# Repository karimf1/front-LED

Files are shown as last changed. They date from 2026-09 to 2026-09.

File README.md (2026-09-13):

# Front LED Light-Bar Holder — Electric Rover

A bracket that carries a Ø50 × 900 mm LED light bar across the front of an
electric rover: a 2 m rail bolted to two chassis pick-up points, with two
split clamps holding the light bar 45 mm above it.

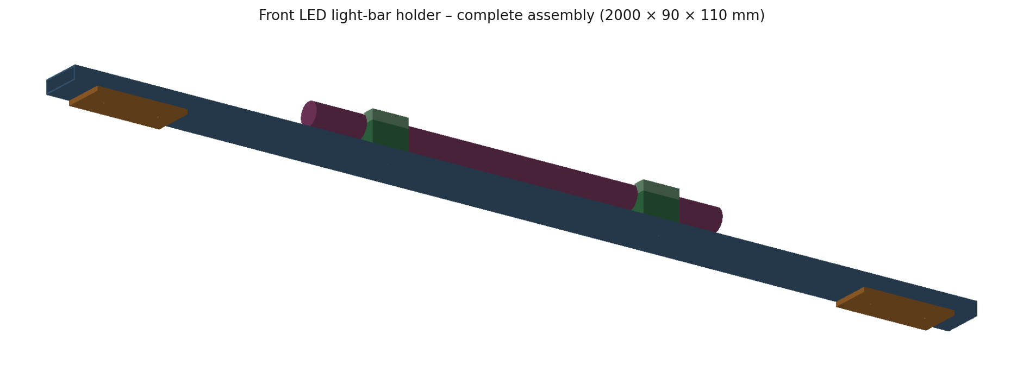
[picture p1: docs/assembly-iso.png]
Assembly


---

## Key features

- **A fully parametric assembly.** Every dimension lives in one parameter block;
  change a number and the whole model — solids, holes, fastener positions,
  drawing sheet — regenerates.
- **A stiffness-driven rail section**, chosen by running the beam case rather
  than by picking a plausible-looking bar.
- **Crush tubes at every bolt**, so the closed rail section survives being
  torqued up.
- **A 2 mm EPDM liner between clamp and light bar**, with the bore opened to
  suit, isolating aluminium from the light-bar housing.
- **An A3 manufacturing drawing generated from the same source as the 3D
  model**, so the sheet and the solids cannot disagree.
- **Two exchangeable rail sections** — the RHS as built, and the original flat
  bar — selectable from one parameter for anyone who wants to see the
  comparison.

---

## The completed design

Origin is the centre of the rail, on its top face. **+X** along the rail,
**+Y** forward (the way the light points), **+Z** up.

| Item | Description | Qty | Material |
|---|---|---|---|
| 1 | Rail, RHS 90 × 30 × 3, 2000 long | 1 | 6061-T6 |
| 2 | Chassis mounting plate 200 × 90 × 10, 2 × Ø11 @ 120 | 2 | 6061-T6 |
| 3 | Clamp saddle 80 × 90 × 45, Ø54 bore | 2 | 6061-T6 |
| 4 | Clamp strap 80 × 90 × 22, Ø54 bore | 2 | 6061-T6 |
| 5 | Crush tube 20 OD × 11 ID × 24 | 4 | 304 stainless |
| 6 | Crush tube 14 OD × 6.6 ID × 24 | 4 | 304 stainless |
| 7 | Bolt M10 × 60, nut + washers | 4 | A2-70 |
| 8 | Bolt M6 × 100, nyloc + washers | 4 | A2-70 |
| 9 | EPDM liner 2 thk × 170 × 80 | 2 | EPDM 60 Sh |
| 10 | LED light bar Ø50 × 900 *(reference)* | 1 | purchased |

Envelope **2000 × 90 × 110 mm**, fabricated mass **6.54 kg** (6.28 kg aluminium
+ 0.26 kg stainless), light bar and fasteners excluded.

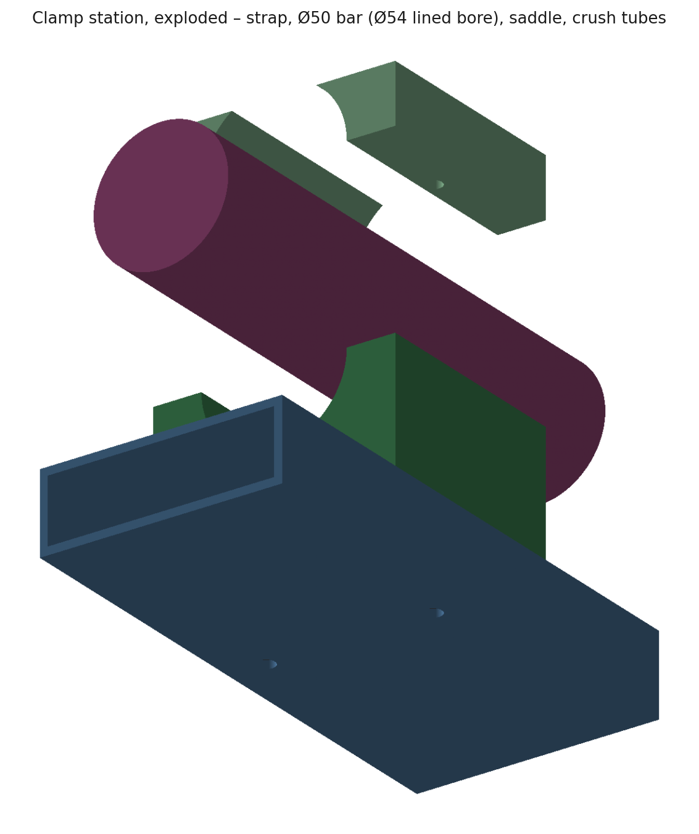
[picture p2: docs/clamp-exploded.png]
Clamp exploded


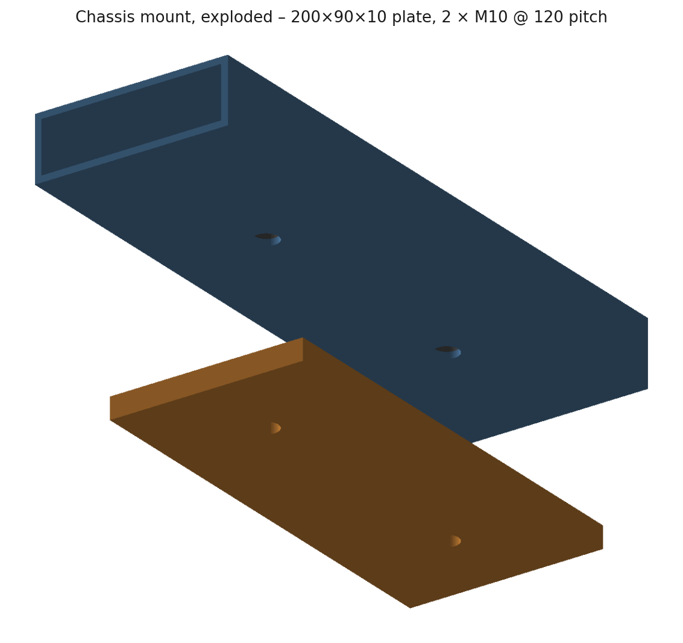
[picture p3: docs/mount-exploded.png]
Chassis mount exploded


## The manufacturing drawing

An A3 sheet drawn 1:1 in millimetres — front elevation and plan at 1:10,
section A-A through a clamp and the chassis plate detail at 1:2, with a title
block, BOM and notes. Dimensions carry a `DIMLFAC` override, so every one reads
the true size of the part despite the view scale.

It exists twice, from the same source:

- **on the `A3 DRAWING` layout of the 3D DWG** — paper space, A3 page already
  set up, so the finished file carries the sheet and the model together.
- **`cad/front-led-mount-drawing.dxf`** — the same sheet in model space as a
  standalone file, for importing into someone else's drawing or handing to a
  shop that does not want the 3D model.

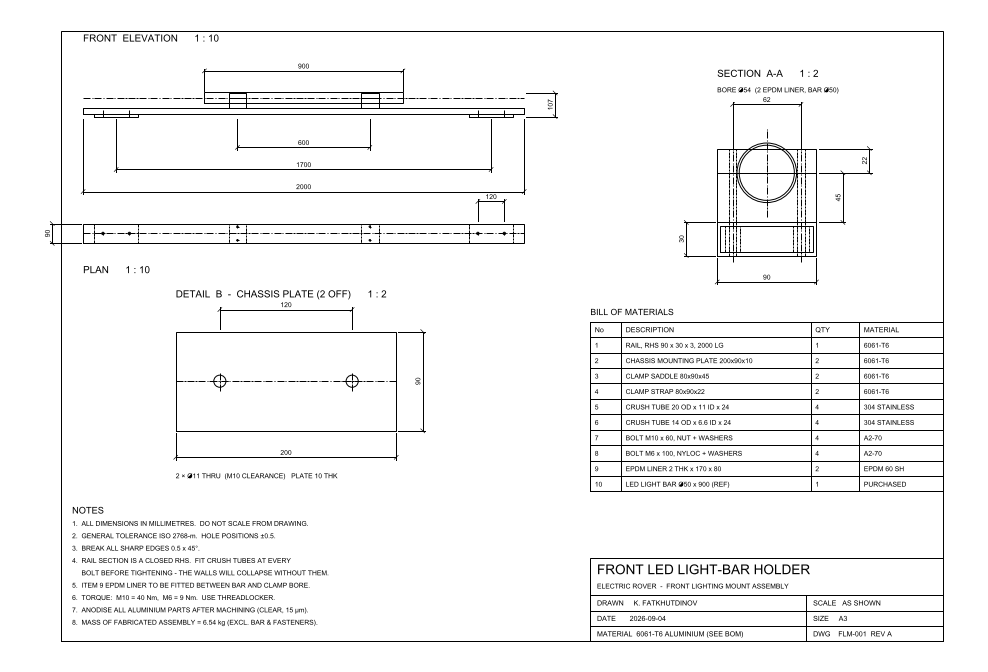
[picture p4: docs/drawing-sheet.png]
Drawing sheet


## Why the model is built by script

The assembly is described by an AutoLISP program rather than placed by hand, and
the parameters live in one block at the top of it. That choice is what makes
decision 1 possible: swapping the rail from flat bar to RHS is one symbol, and
the plates, the crush tubes, the bolt lengths and the drawing sheet all follow.
Hand-modelled, that comparison would have been a day's rework and would
therefore not have been made.

The same parameters are mirrored in `params.py`, which drives the drawing
generator — so the sheet's dimensions come from the same numbers as the solids
rather than from someone reading them off the model.

---

## Next steps and possible improvements

- **Confirm the light bar's actual mass**; 2.5 kg is assumed. Deflection and
  first-mode frequency scale roughly with √mass, so a 4 kg bar moves the 26 Hz
  result to about 21 Hz.
- **Run a proper modal analysis if the rover sees sustained excitation above
  ~15 Hz.** The 26 Hz figure is a hand calculation on a uniform beam with
  distributed mass; the real structure has two discrete clamp masses and a bar
  that contributes its own stiffness.
- **Add a slotted adjustment in the saddle** if the light bar needs aiming after
  mounting. The aim is presently fixed by the bore axis, which means getting it
  wrong is a re-machining job rather than a spanner job.
- **Reconsider the mount span.** 1700 mm between supports is inherited from the
  original construction lines. Moving the plates outboard is the cheapest
  remaining stiffness gain available — deflection goes as span⁴ between
  supports — and costs nothing but chassis pick-up points.
- **Check the bolted joint properly.** The crush tubes make the joint sane, but
  no preload, slip or bearing calculation has been done; the M10s are sized by
  convention rather than by analysis.
- **Add a drainage path.** A 2 m closed section pointing into the weather on a
  rover will collect water at one end. A small hole at the low point costs
  nothing and is easier to add now than after anodising.
- **Corrosion at the aluminium/stainless interface.** The crush tubes sit
  directly in the aluminium rail. For anything other than dry-weather use, an
  insulating washer or a coated sleeve is worth the extra part number.

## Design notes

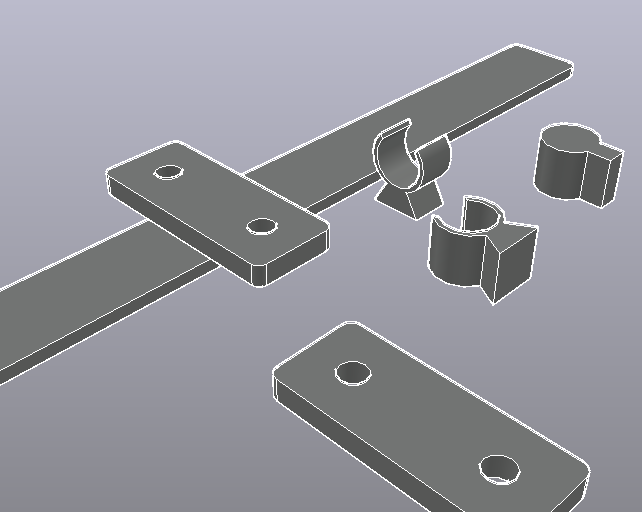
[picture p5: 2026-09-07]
docs/original-model-preview.png

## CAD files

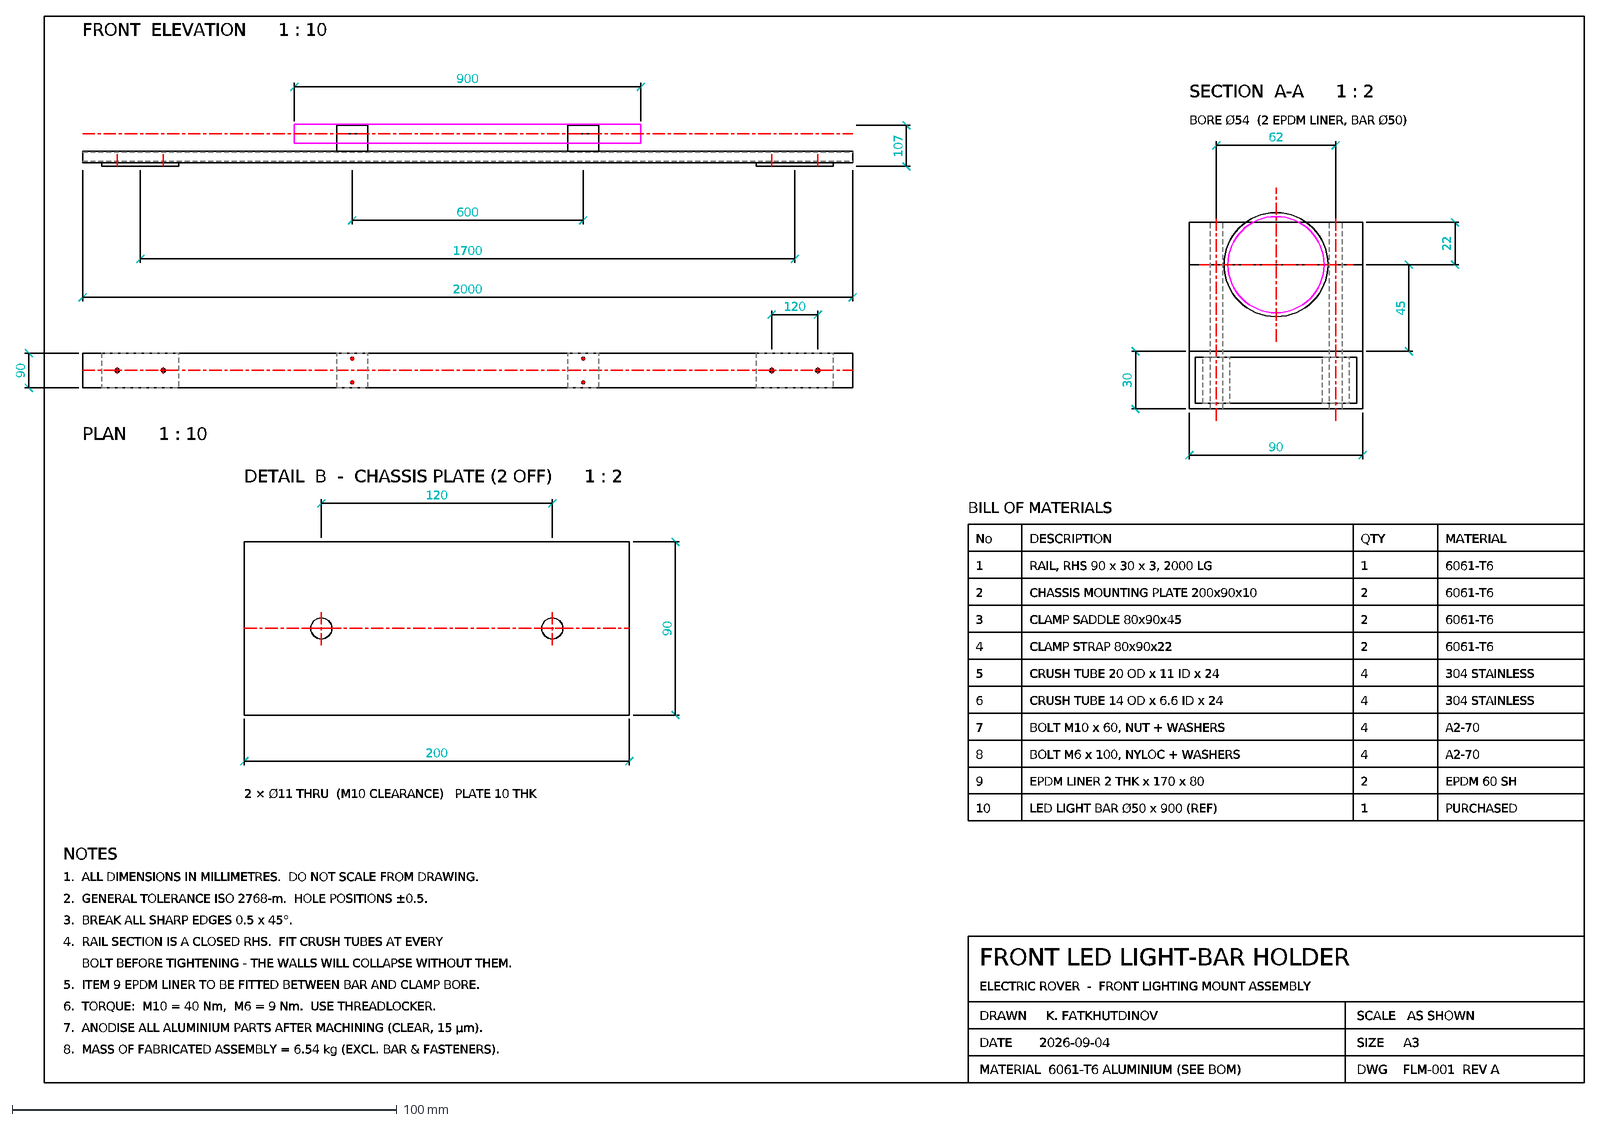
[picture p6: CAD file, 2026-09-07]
front-led-mount-sheet-A3.dxf
2000
1700
600
900
107
FRONT ELEVATION 1 : 10
90
120
PLAN 1 : 10
62
30
45
22
SECTION A-A 1 : 2
BORE Ø54 (2 EPDM LINER, BAR Ø50)
200
DETAIL B - CHASSIS PLATE (2 OFF) 1 : 2
2 × Ø11 THRU (M10 CLEARANCE) PLATE 10 THK
FRONT LED LIGHT-BAR HOLDER
ELECTRIC ROVER - FRONT LIGHTING MOUNT ASSEMBLY
DRAWN K. FATKHUTDINOV
DATE 2026-09-04
MATERIAL 6061-T6 ALUMINIUM (SEE BOM)
SCALE AS SHOWN
SIZE A3
DWG FLM-001 REV A
No
DESCRIPTION
QTY
MATERIAL
1
RAIL, RHS 90 x 30 x 3, 2000 LG
6061-T6
2
CHASSIS MOUNTING PLATE 200x90x10
3
CLAMP SADDLE 80x90x45
4
CLAMP STRAP 80x90x22
5
CRUSH TUBE 20 OD x 11 ID x 24
304 STAINLESS
6
CRUSH TUBE 14 OD x 6.6 ID x 24
7
BOLT M10 x 60, NUT + WASHERS
A2-70
8
BOLT M6 x 100, NYLOC + WASHERS
9
EPDM LINER 2 THK x 170 x 80
EPDM 60 SH
10
LED LIGHT BAR Ø50 x 900 (REF)
PURCHASED
BILL OF MATERIALS
NOTES
1. ALL DIMENSIONS IN MILLIMETRES. DO NOT SCALE FROM DRAWING.
2. GENERAL TOLERANCE ISO 2768-m. HOLE POSITIONS ±0.5.
3. BREAK ALL SHARP EDGES 0.5 x 45°.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

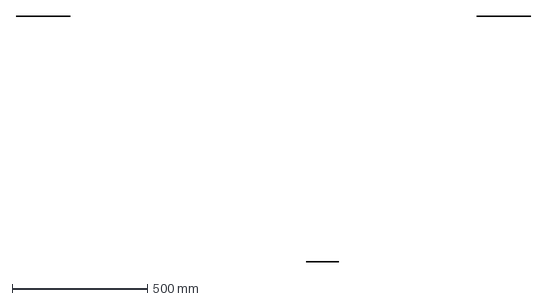
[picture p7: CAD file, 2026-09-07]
front-LED_ORIGINAL-decoded.dxf
1900.0 x 906.5 mm

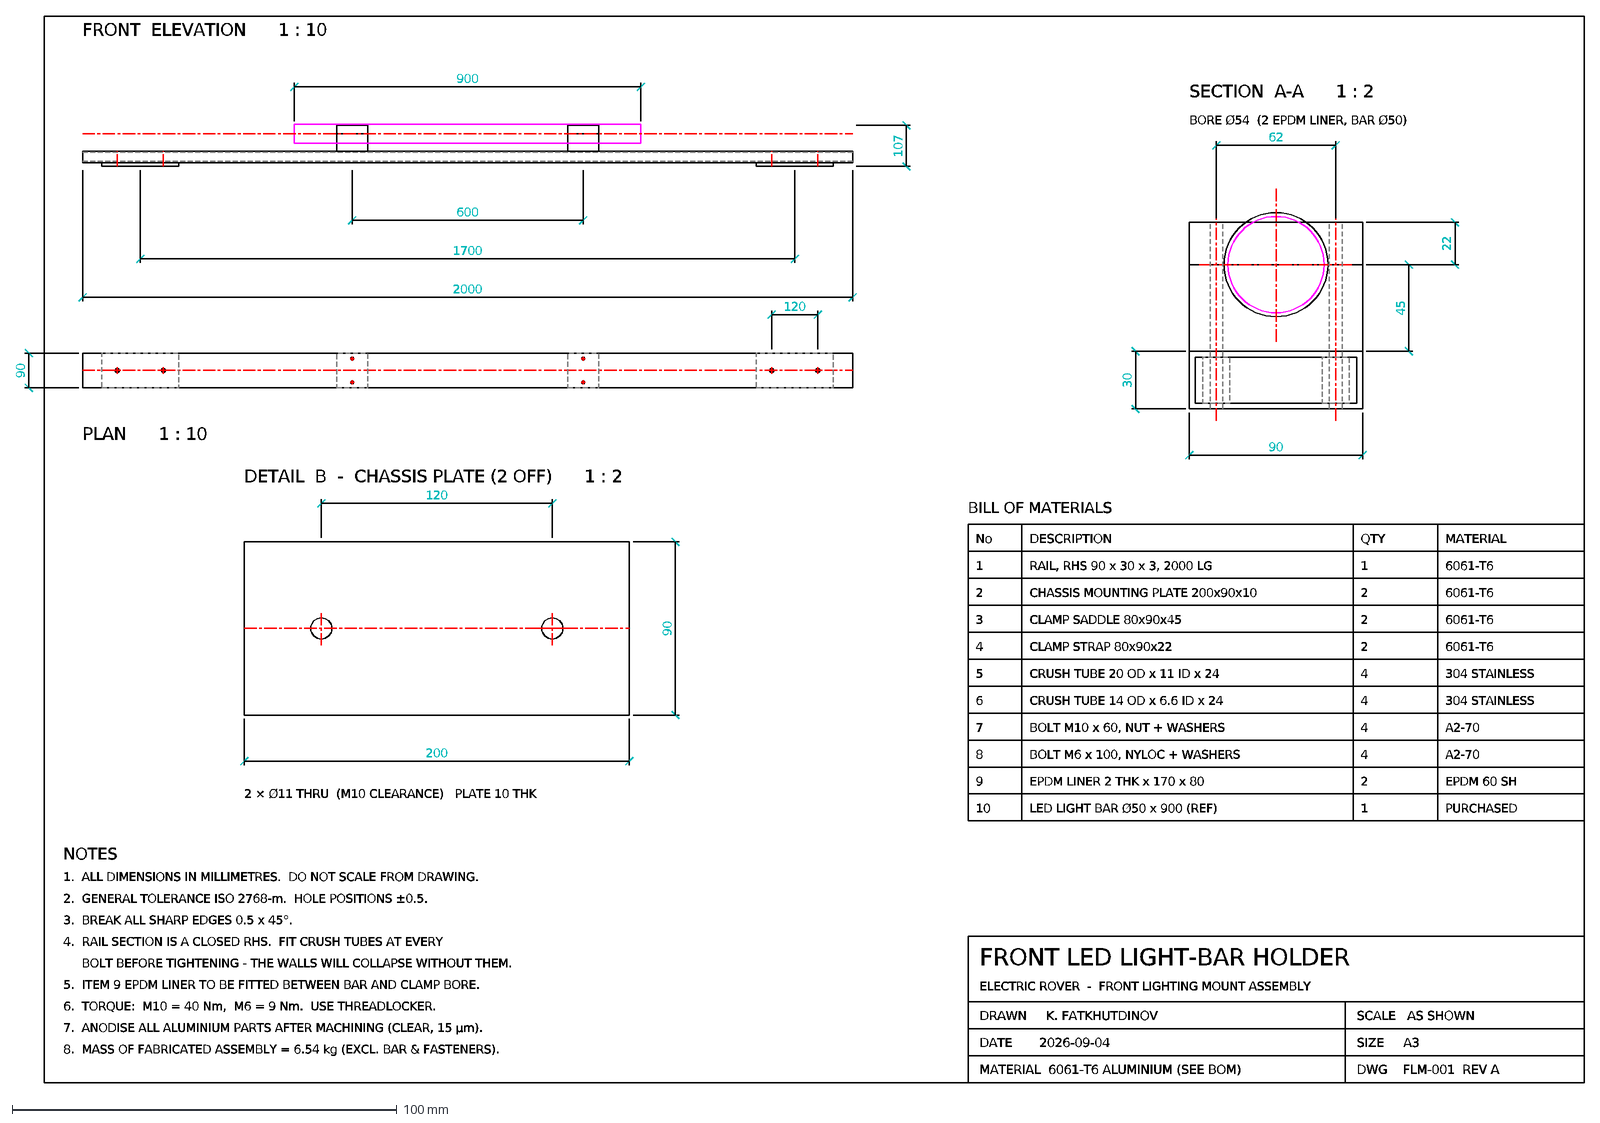
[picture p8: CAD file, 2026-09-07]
front-led-mount-drawing.dxf
2000
1700
600
900
107
FRONT ELEVATION 1 : 10
90
120
PLAN 1 : 10
62
30
45
22
SECTION A-A 1 : 2
BORE Ø54 (2 EPDM LINER, BAR Ø50)
200
DETAIL B - CHASSIS PLATE (2 OFF) 1 : 2
2 × Ø11 THRU (M10 CLEARANCE) PLATE 10 THK
FRONT LED LIGHT-BAR HOLDER
ELECTRIC ROVER - FRONT LIGHTING MOUNT ASSEMBLY
DRAWN K. FATKHUTDINOV
DATE 2026-09-04
MATERIAL 6061-T6 ALUMINIUM (SEE BOM)
SCALE AS SHOWN
SIZE A3
DWG FLM-001 REV A
No
DESCRIPTION
QTY
MATERIAL
1
RAIL, RHS 90 x 30 x 3, 2000 LG
6061-T6
2
CHASSIS MOUNTING PLATE 200x90x10
3
CLAMP SADDLE 80x90x45
4
CLAMP STRAP 80x90x22
5
CRUSH TUBE 20 OD x 11 ID x 24
304 STAINLESS
6
CRUSH TUBE 14 OD x 6.6 ID x 24
7
BOLT M10 x 60, NUT + WASHERS
A2-70
8
BOLT M6 x 100, NYLOC + WASHERS
9
EPDM LINER 2 THK x 170 x 80
EPDM 60 SH
10
LED LIGHT BAR Ø50 x 900 (REF)
PURCHASED
BILL OF MATERIALS
NOTES
1. ALL DIMENSIONS IN MILLIMETRES. DO NOT SCALE FROM DRAWING.
2. GENERAL TOLERANCE ISO 2768-m. HOLE POSITIONS ±0.5.
3. BREAK ALL SHARP EDGES 0.5 x 45°.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

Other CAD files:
front-led-mount-3D.dwg

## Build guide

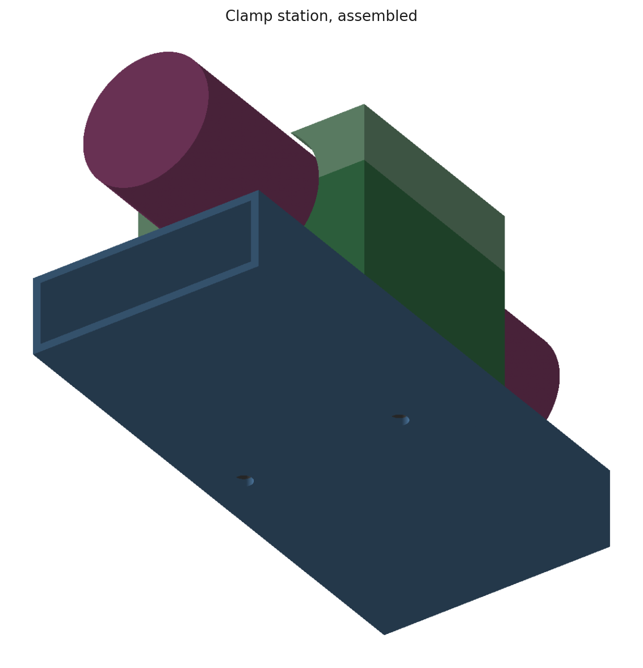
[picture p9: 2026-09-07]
docs/clamp-assembled.png
